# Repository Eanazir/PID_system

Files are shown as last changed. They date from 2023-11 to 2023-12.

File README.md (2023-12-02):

# PID Ball Balancing System

This project is a PID (Proportional, Integral, Derivative) control system designed to balance a ball on a platform. The system utilizes a Raspberry Pi 3 and servo motors to adjust the platform's angle in real-time, maintaining the ball's position.

## Images

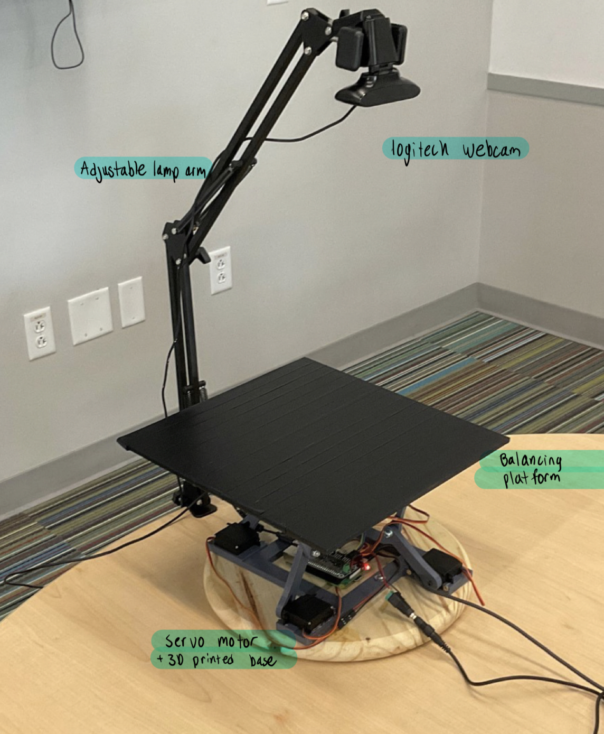
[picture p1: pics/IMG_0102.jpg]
System Overview

*System overview with labeled components.*

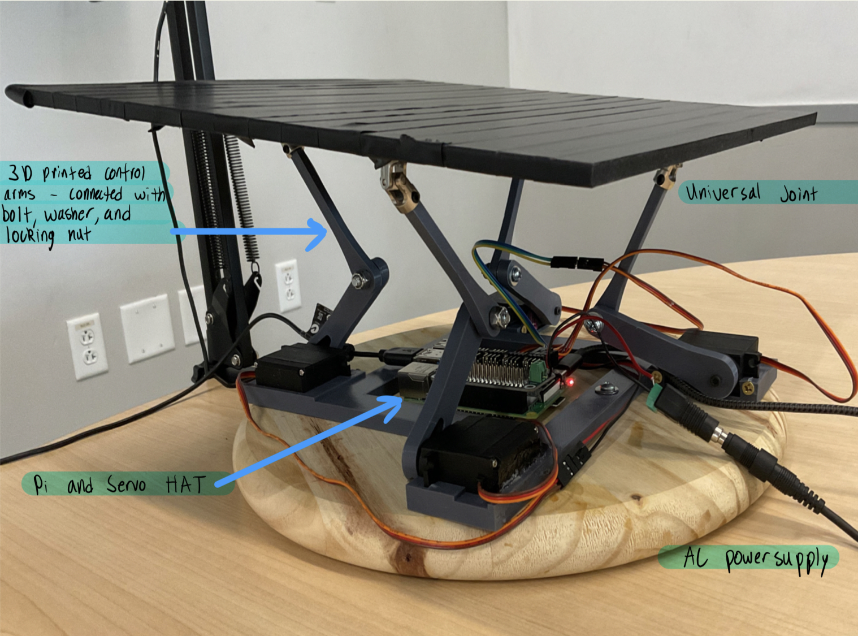
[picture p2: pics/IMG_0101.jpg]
Action Shot

*The PID Ball Balancing System in operation.*

## Bill of Materials

Below is a list of components used in the PID Ball Balancing System, along with their sources and prices.

| Item | Quantity | Source | Price |
|---|---|---|---|
| Servo Motors | 4 | [Amazon](#) | $18.39 |
| Servo Driver HAT | 1 | [Amazon](#) | $18.20 |
| 3D Printed Motor Arm | 4 | FEDC Design Center | N/A |
| 3D Printed Arm | 4 | FEDC Design Center | N/A |
| 3D Printed Base | 1 | FEDC Design Center | N/A |
| 3D Printed Couplers | 4 | FEDC Design Center | N/A |
| Universal Joints | 4 | [Amazon](#) | $10.99 |
| Raspberry Pi 3 | 1 | Provided | N/A |
| Washer Locking Nut Bolt | 4 | [Home Depot](#) | ~$6.00 |
| Wooden Base | 1 | [Home Depot](#) | ~$12.00 |
| Sq. Foot PVC Platform | 1 | [Amazon](#) | $17.47 |
| Adjustable Lamp Arm | 1 | [Amazon](#) | $19.47 |
| Logitech Webcam | 1 | [Amazon](#) | $59.99 |
| 9 V 1 A Power Supply | 1 | Provided | N/A |

## Setup and Configuration

The system's hardware assembly involves mounting the servo motors on the 3D-printed base, connecting the arms, and positioning the Raspberry Pi and camera. Detailed steps for assembly and the software setup can be found in our [Github repository](https://github.com/Eanazir/PID_system).

## System Operation

The PID controller software processes the camera feed to track the ball's position and adjusts the platform's angle using the servo motors to keep the ball centered.

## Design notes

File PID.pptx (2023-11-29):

## PID Ball Balancing

CSCE 462: Eyad Nazir & Hyder Ochsner

## Background

The concept of dynamic stabilization, exemplified in our PID Ball Balancing
project, is a significant leap in control engineering. Drawing inspiration
from advanced earthquake stabilization systems used in modern
infrastructure, this project aims to dynamically control the position
of a ball on a flat surface using a Proportional-Integral-Derivative (PID)
controller. The interplay of hardware components, like servo motors,
and sophisticated software algorithms, echoes the principles of seismic
dampers in skyscrapers. These systems counteract disturbances, such as
seismic waves, by adjusting their structure in real-time. Our project,
while on a smaller scale, mirrors this intricate balance of mechanics and
electronics, and serves as an educational tool in understanding the fundamental principles of vibration control and feedback systems in civil engineering.

## Project goals

- Develop and construct a PID Ball Balancing System to demonstrate the principles of Proportional-Integral-Derivative (PID) control in a hands-on way.
- Integrate mechanical, electrical, and software components to create a dynamic system capable of stabilizing a ball on a tilting platform, showcasing real-world engineering applications.
- Design and implement custom CAD parts, including Motor and Free Arms, for precise system assembly, fostering practical skills in mechanical design and 3D printing.

## System Design

Motor Arm and Free Arm Design
Base Assembly
Motor Bracket Design
Prototype Construction
Circuitry
Software

## Parts Used


- Universal Joint
- Control arms
- AC power Supply
- Raspberry PI 3
- Servo Hat
- Balancing platform
- Servo Motor
- 3d-printed Base
- Adjustable Lamp Arm
- Logitech Camera

## Construction

Pictures along the process

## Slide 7

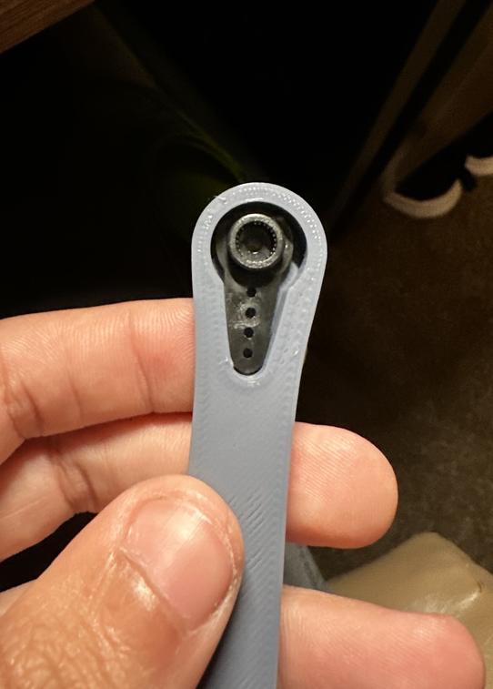
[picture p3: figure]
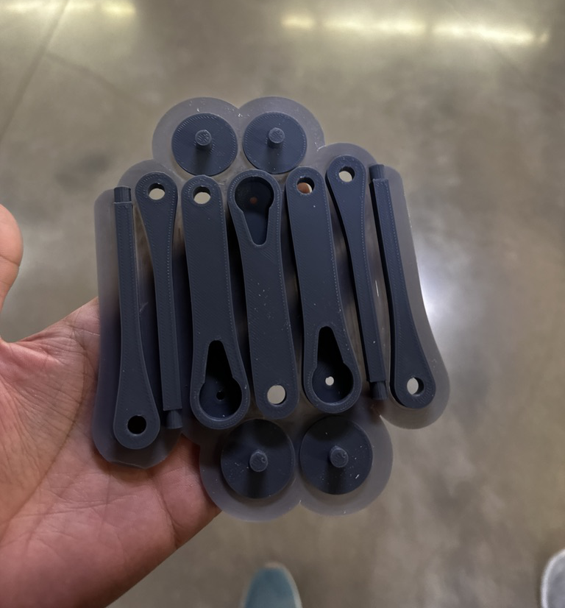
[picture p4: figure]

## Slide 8

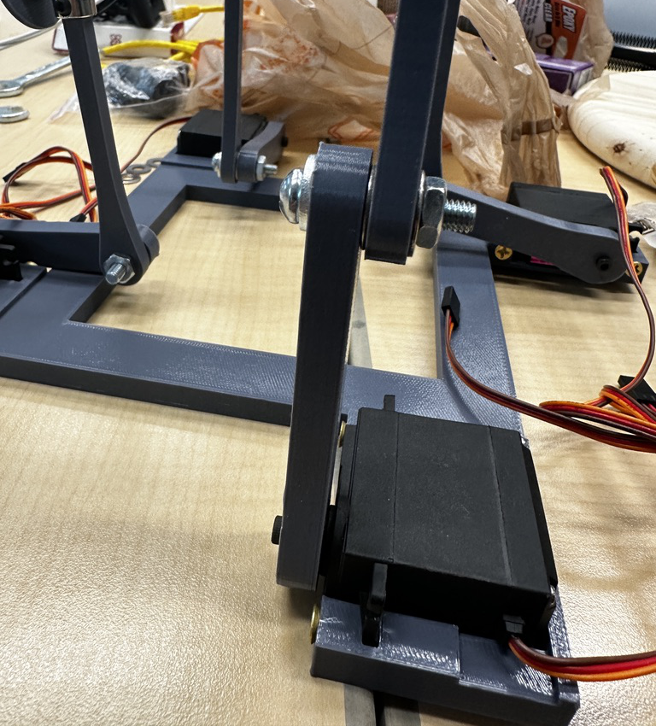
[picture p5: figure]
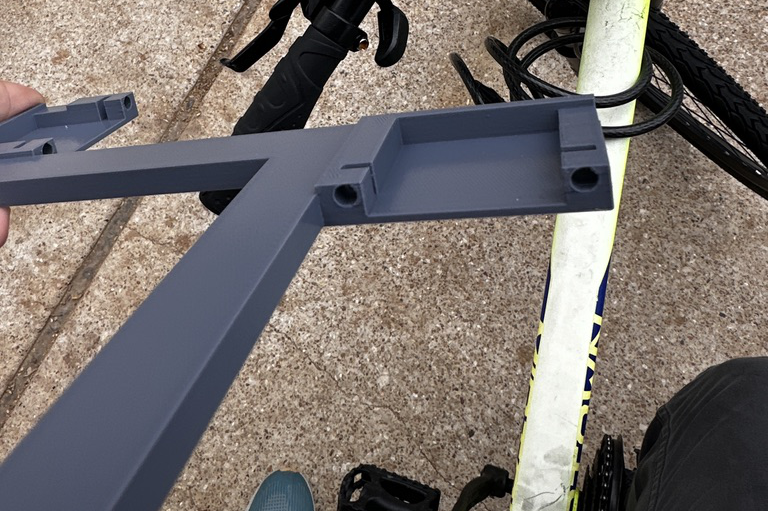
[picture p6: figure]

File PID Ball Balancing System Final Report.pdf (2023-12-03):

# PID Ball Balancing System

# Final ProjectReport Fall 2023

## Hyder Ochsner - Hyder.ochsner@tamu.edu Eyad Nazir - Eanazir@tamu.edu

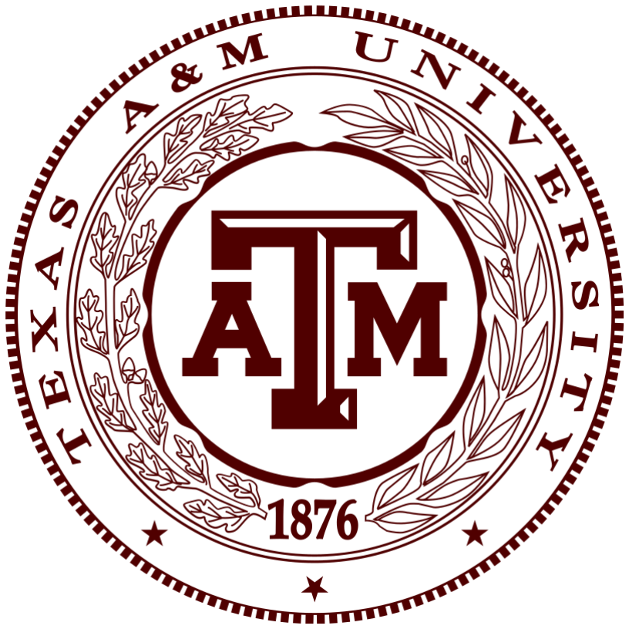
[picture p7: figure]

## Table Of Contents

1. Summary and High-level Description
2. Background
3. Introduction
a. Purpose
b. Environment
c. Constraints
4. System Design
a. Hardware/Mechanical Components
b. Software
5. Design Process
a. Motor Bracket Design
b. Motor Arm and Free Arm Design
c. Base Assembly
d. Prototype Construction
e. Circuitry
f. Software
6. Bill of Materials
7. Appendix (PID Model/Github Link)

Summary and High-level Description

The Ball Balancing PID System project focuses on achieving stabilization and control of a ball on a flat surface through a feedback mechanism. The primary objective is to maintain the ball at a predefined location by continuously measuring its position and adjusting the orientation of the surface. The chosen control mechanism for this project is the Proportional-Integral-Derivative (PID) controller, a widely used feedback controller in industrial control systems. The values calculated by the PID controller are then translated to the angles of the servo motors. Thus allowing for movement of the balancing platform. The project is designed to offer valuable insights into feedback control systems and serves as a practical introduction to PID control, a foundational concept in control engineering.

Background

The concept of dynamic stabilization, exemplified in our PID Ball Balancing project, is a significant leap in control engineering. Drawing inspiration from advanced earthquake stabilization systems used in modern infrastructure, this project aims to dynamically control the position of a ball on a flat surface using a Proportional-Integral-Derivative (PID) controller. The interplay of hardware components, like servo motors, and sophisticated software algorithms, echoes the principles of seismic dampers in skyscrapers. These systems counteract disturbances, such as seismic waves, by adjusting their structure in real-time. Our project, while on a smaller scale, mirrors this intricate balance of mechanics and electronics, and serves as an educational tool in understanding the fundamental principles of vibration control and feedback systems in civil engineering.

Introduction

Purpose
The PID Ball Balancing System, initially developed as a collaborative engineering project, has gained recognition for its educational potential and will be used to provide students with a tool to visualize PID controls, addressing a key engineering problem. By integrating a Raspberry Pi with mechanical components to balance a ball on a tilting platform, the project offers a tangible demonstration of control systems in action. This hands-on approach aids in demystifying complex engineering concepts, particularly in control and feedback mechanisms. As an instructional tool, it not only enhances learning but also encourages innovative thinking in addressing real-world engineering challenges, making it a valuable addition to the educational landscape in engineering and technology.

Environment
The PID Ball Balancing System integrates mechanical, electrical, and software components within a cohesive environment. Its mechanical aspects, primarily the platform and servo motors, interface directly with the physical world. The system's operation is confined within its structured design, encompassing a Raspberry Pi, sensors, and actuators, ensuring stability and precision in its function.

Constraints
The system has a few limiting factors:
1. The Ball needs not to be thrown too fast as the platform will not have the chance to react due to the 60fps nature of the camera
2. The Ball needs not to be thrown at an excessive speed leading it to fall of the platform very quickly
3. The Ball needs to have a desired weight to ensure it does not roll too fast due to the low friction of the platform

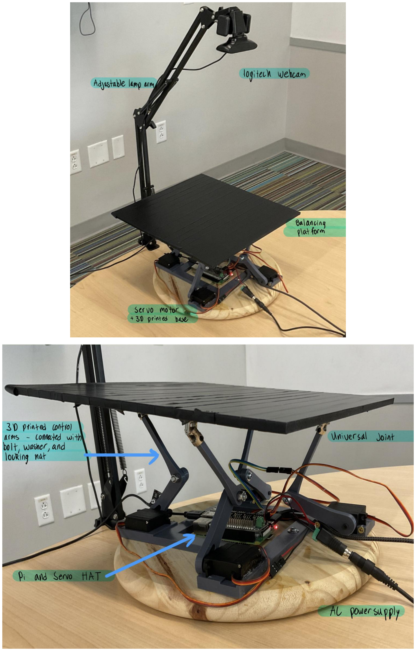
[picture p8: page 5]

System Design

Hardware/Mechanical Components

The system's functionality relies on three main components: servo motors for platform control, the balancing platform, and a camera for ball position tracking. To ensure connectivity between these components, various subcomponents are integrated into the system.

1. Servo Motors and Mounting
The servo motors are mounted on a solid surface to ensure stability during operation. A solid wood plank with a 3D printed bracket is utilized for this purpose. The bracket includes evenly spaced mounts for the four servo motors, each fastened securely to the mount with two screw holes. This configuration eliminates unwanted position shifts of our motors during execution. .
2. Platform Design and Connection to Motors
The platform consists of a lower arm connected to an upper arm at a movable joint, both 3D printed and fastened together using a bolt, washer, and locking nut. The upper arm connects to the platform through a universal joint, allowing the platform to move while maintaining a stable connection with the arm. This design ensures flexibility and stability in the system.
3. Camera Positioning
The camera is positioned above the platform to capture the ball's movement fully and is stabilized to reduce variability. An adjustable lamp arm with a clamp is used for this purpose, providing a steady and adjustable position on the table.

In essence, the hardware and mechanical components are intricately designed and assembled to create a robust system capable of implementing the PID control mechanism for ball balancing. Each component plays a crucial role in ensuring the system's stability and effectiveness in maintaining the ball at the desired location on the flat surface.

Software
The software component of the PID Ball Balancing System is a blend of image processing for ball tracking and intricate PID control logic. This combination exemplifies the project's technical sophistication and educational value.
Image Processing and Ball Tracking: The system uses OpenCV for real-time image analysis. It identifies the ball's position on the platform by analyzing video feed from a camera interfaced with the Raspberry Pi. Our code implements functions to recognize circular shapes and filter out irrelevant contours, ensuring accurate ball tracking. This is crucial for determining the ball's deviation from the desired position. In addition we dynamically search for the center of the platform using contours. We then compare the two centers to find the error.
PID Controller: The core of our system is the PID controller algorithm. The Proportional, Integral, and Derivative components are meticulously tuned to achieve optimal system response. We engaged in an iterative process to determine the PID constants, adjusting them based on the system's performance in various test scenarios.
- Proportional (P) Term: It calculates an output proportional to the current error (the difference between the desired and actual ball position). We experimented with different values to find a balance that minimizes overshoot yet responds swiftly to disturbances.
- Integral (I) Term: This term accumulates the past errors to eliminate residual steady-state error. Finding the right integral constant was crucial to prevent integral windup and ensure smooth corrections over time.
- Derivative (D) Term: It predicts future error trends based on their rate of change, providing damping and improving system stability. Our adjustments in the derivative constant aimed to counteract the ball's motion effectively without inducing unnecessary oscillations.
Our code's sophistication lies in integrating these elements into a cohesive system. We programmed the Raspberry Pi to process the image data, calculate the error in the ball's position, and generate control signals for the servo motors. This interactive loop of sensing, computing, and actuating embodies the intricacies of modern control systems.

Design Process

Stage one: Motor Bracket Design
Upon gathering all the required components for our project, we soon recognized the necessity of custom CAD (Computer-Aided Design) parts for optimal functionality. Our immediate focus was on designing a Motor Bracket, a critical component tasked with securing the servo motors firmly to the base. Given the servos' rapid and continuous movement, precision in the bracket's design was paramount to ensure stable operation without any interference.

Our initial prototype of the Motor Bracket revealed a slight miscalculation: the back-side was designed 2 millimeters too short, resulting in an improper fit for the motors. To rectify this, we quickly adapted our design and extended the back-side by 2 millimeters, ensuring a snug and accurate fit. This adjustment was crucial; it highlighted the importance of precision in mechanical design, especially in a system where even minor discrepancies could significantly impact performance. The redesigned bracket was then 3D printed, marking a successful step in the iterative process of engineering and design refinement. We would then have to come back to add it to the base assembly.

Stage two: Motor Arm and Free Arm Design
Motor Arm is the arm connected to the motor with a very small bolt and then connected to that arm is the Free Arm in which it is held loosely to the Motor arm allowing the flexing and movement of the platform easily. Our initial task was to CAD design the Motor Arm for a precise fit with the motor's hole. However, budget constraints precluded us from producing a high-fidelity print with integrated threads. This limitation led to an issue where the motor shaft would rotate, but the arm remained stationary due to the absence of threads. To overcome this, we revised the design to include a cutout for the Horn, which would be attached directly to the motor. The Motor Arm was then designed to mount onto this Horn, ensuring synchronized movement.

Once this prototype was successfully printed, we proceeded to design and print the Free Arm. This part required only a single iteration, featuring holes at each end for attachment to the Motor Arm and a universal joint, respectively.

We initially used a standard nut to connect the two arms with a bolt and washer. However, we encountered a problem where the rotation of the arm caused the nut to loosen and unscrew. To resolve this, we switched to a locking nut, which provided the necessary stability and prevented the disassembly of the bolt during operation. This adjustment was a critical step in ensuring the reliability and effectiveness of our design.

Stage three: Base Assembly
Following the successful verification of our prototyped parts for fit and compatibility, we shifted our focus to the final CAD assembly, integrating the Motor Brackets with the 6-inch by 6-inch square base. The design called for the placement of one bracket on each side of the base, arranged in a clockwise direction for balanced support and operational efficiency. Each bracket, measuring 2-inches in width, contributed to the total dimensions, extending the length and width of the base to 8-inches at its widest points. This careful consideration in the design ensured a robust and stable structure, essential for the smooth functioning of our system.

Stage four: Prototype Construction
Upon acquiring the essential components, including a wooden base, a base for holding the motors, four Motor Arms, four Free Arms, and some universal joints, we commenced the assembly of our prototype. However, during the construction process, we identified the need for a coupler to link the base with the universal joints. This coupler was designed with one circular end to attach to the joint and another end to be adhered to the platform, which we determined should measure 12 inches by 12 inches for optimal balance and space.
The assembly of the prototype involved meticulously fitting all the arms together using bolts and screws. To enhance the structure's stability, we decided to secure the 3D-printed base to the wooden base using two screws. This step was crucial in ensuring that the base remained firmly anchored, providing a solid foundation for the system's operation and preventing any unwanted movement or instability during testing.
Stage five: Circuitry
The circuitry of our system includes: four servo motors and the servo driver HAT. Upon connecting our components and simple testing, we discovered the motors were not acting as expected as the RaspberryPi’s power source did not produce enough current to power the motors and the Pi. As a result, we connected a power source directly to the servo HAT. After experimenting with multiple 9 V batteries, we concluded the need for AC power supply. We obtained a 9 V, 1 A power supply and the motors performed as expected.

Stage six: Software
The software of our system contains two main components: the PID controller and image processing. We began by researching the necessary libraries and determined the ADAFRUIT Servo library and OpenCV would suffice. We first developed the ball tracking software aimed at detecting the center of our balancing platform and the center of the ping pong ball. We faced numerous challenges due to variations in lighting. To overcome these, we added adjustable options within our program like the ability to select the color of the ball being used and a slider to adjust the brightness threshold.
The PID controller required numerous iterations as the system relies heavily on trial and error.

Bill of Materials

Item | Source | Price
(4x) Servo motors | Amazon (https://www.amazon.com/dp/B0BYD9M1P3?psc=1&ref=ppx_yo2ov_dt_b_product_details) | $18.39
Servo driver HAT | Amazon (https://www.amazon.com/dp/B0BS8PLYZC?psc=1&ref=ppx_yo2ov_dt_b_product_details) | $18.20
(4x) 3D printed Motor Arm | FEDC Design Center | N/A
(4x) 3D printed Free Arm | FEDC Design Center | N/A
3D printed Base | FEDC Design Center | N/A
(4x) 3D printed couplers | FEDC Design Center | N/A
(4x) Universal joints | Amazon (https://www.amazon.com/dp/B07V9NW3V8?ref=ppx_yo2ov_dt_b_product_details&th=1) | $10.99
Raspberry Pi 3 | Provided | N/A
(4x) Washer, locking nut, bolt | Home Depot | ~ $6.00
Wooden base | Home Depot | ~ $12.00
Sq. foot PVC platform | Amazon (https://www.amazon.com/dp/B08N7YJKWD?psc=1&ref=ppx_yo2ov_dt_b_product_details) | $17.47
Adjustable lamp arm | Amazon (https://www.amazon.com/dp/B07X3KMYW2?psc=1&ref=ppx_yo2ov_dt_b_product_details) | $19.47
Logitech webcam | Amazon (https://www.amazon.com/Logitech-C920x-Pro-HD-Webcam/dp/B085TFF7M1?s=electronics) | $59.99
9 V, 1 A power supply | Provided | N/A

Appendix (PID Model/Github Link)
- Github link: https://github.com/Eanazir/PID_system

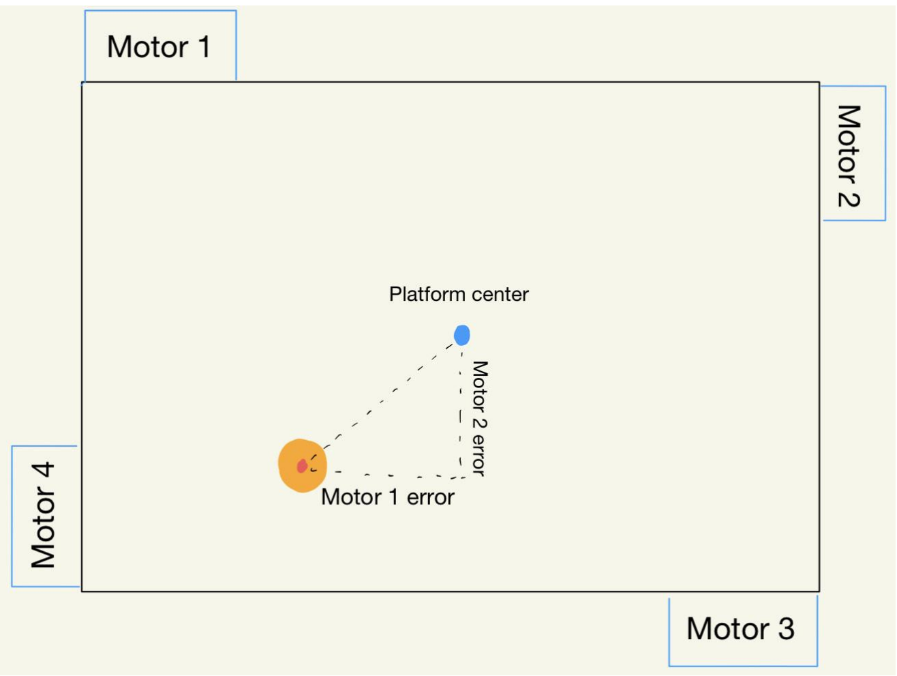
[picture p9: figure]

- Error Calculation:
- Motor 1 (Top edge) Error[1] = Ball | :
y − Platformy
calculates the vertical distance between the ball's current and desired positions. A positive error indicates the ball is below the desired position, requiring the top edge to lift.
- Motor 2 (Right edge) Error[2] = Ball | :
x − Platformx
measures the horizontal distance on the right side. A positive error suggests the ball is left of the desired position, necessitating the right edge to lift.
- Motor 3 (Bottom edge): Error[3] = Platform | : y − Ball y
is similar to Motor 0 but for the bottom edge. A positive error means the ball is above the desired position, signaling the bottom edge to lift.
- Motor 4 (Left edge): Error[4] = Platformx − Ball
| x :
assesses the horizontal distance on the left side. A positive error indicates the ball is to the right of the desired position, requiring the left edge to lift.

- PID = K
p

× Error + K
i

× ∫ Error dt + Kd
×

d(Error)
dt
- Proportional (P) Term (Kp): Determines the reaction to the current error. If the ball is far from the desired position, a large correction is made.
- Integral (I) Term (Ki): Addresses the accumulation of past errors (integral of the error), helping to eliminate residual steady-state error.
- Derivative (D) Term (Kd): Predicts future error trajectory based on its rate of change, providing a dampening effect to avoid overshooting.
- The PID value would be negative when the motor needed to tilt the platform up and positive when the motor needed to tilt the platform down.
Note: The tuning process is often iterative, and it involves finding the right balance between the three terms to achieve stability, fast response, and minimal overshoot or oscillation. This process relies heavily on trial and error.
- New Angle = Initial Angle +

PID
Scaling Factor
- The New Angle here is calculated based on its initial angle plus the PID number divided by a scaling factor that was obtained by trial and error. This was done for each motor.
- For our hardware as the angle increased the motor arm went down decreasing the platform level.

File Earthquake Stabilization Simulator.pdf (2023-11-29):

## Earthquake Stabilization Simulator

Team Members:
- Hyder Ochsner - System Design Engineer: (hyder.ochsner@tamu.edu)
- Responsibilities:
■ Responsible for the overall system architecture, component selection, and ensuring that all components work together seamlessly
- Eyad Nazir - Software & Control Engineer: (eanazir@tamu.edu)
- Responsibilities:
■ Responsible for writing the software that will run on the microcontroller, implementing the PID algorithm, and programming any additional features such as the bouncing patterns
Summary:
The Ball Balancing PID System project aims to stabilize and control the position of a ball on a flat surface using a feedback mechanism. By constantly measuring the ball's position and adjusting the surface's orientation, the system maintains the ball at a predefined location, even when disturbed. The control mechanism employed is a Proportional-Integral-Derivative (PID) controller, a popular type of feedback controller in industrial control systems. This project provides valuable insights into feedback control systems and can serve as a practical introduction to PID control, one of the foundational concepts in control engineering.

Technical Description:
1. Components:
- Platform: A flat surface on which the ball rolls. This can be controlled using actuators to tilt in various directions
- Ball: A spherical object that rolls on the platform
- Sensors: To detect the ball's position. Common choices include infrared sensors, ultrasonic sensors, or cameras
- Actuators: Mechanisms that can tilt the platform in response to control signals. Typically, servos or motors are used
- Microcontroller: A device that processes sensor data, implements the PID algorithm, and controls the actuators
2. Working:
- The sensors constantly measure the ball's position on the platform and send this data to the microcontroller
- The microcontroller calculates the error, which is the difference between the ball's current position and the desired position
- Using the PID algorithm, the controller calculates the necessary adjustments to make to the platform's orientation

- The actuators adjust the platform's tilt based on the controller's signal, moving the ball towards the desired position
3. PID Controller:
- Proportional (P): This component produces an output value proportional to the current error. It determines the reaction to the current error
- Integral (I): Concerned with the accumulation of past errors. If the error has been present for an extended period, it will accumulate (integral of the error), and the controller will respond by changing the control output in relation to a sustained error
- Derivative (D): This predicts the future error trajectory based on its rate of change. It provides a control output to counteract the rate of error change
4. Features:
- To design and develop a system that can dynamically adjust its position to counteract disturbances, simulating the behavior of advanced earthquake stabilization systems used in modern infrastructure
- System will include programmed bouncing patterns which when executed will bounce the ball in a predefined rhythm
- Sync the bouncing action with music or sound effects. For example, the ball can bounce to the beat of a song, turning the system into an interactive musical instrument

High-level design:

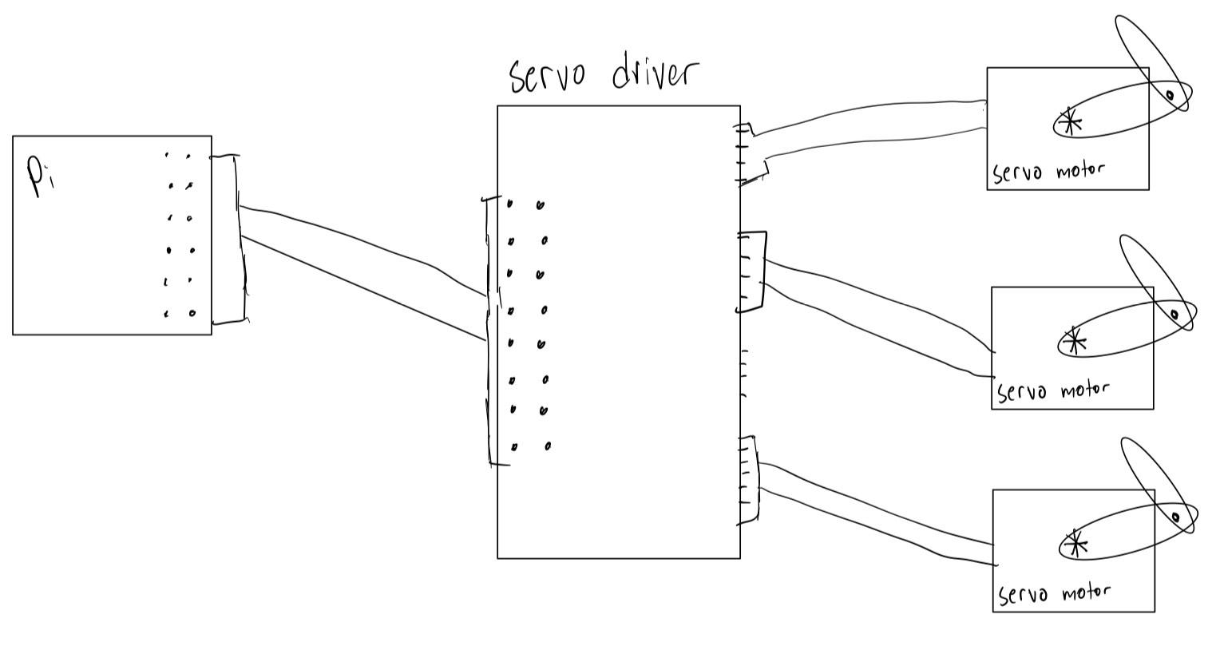
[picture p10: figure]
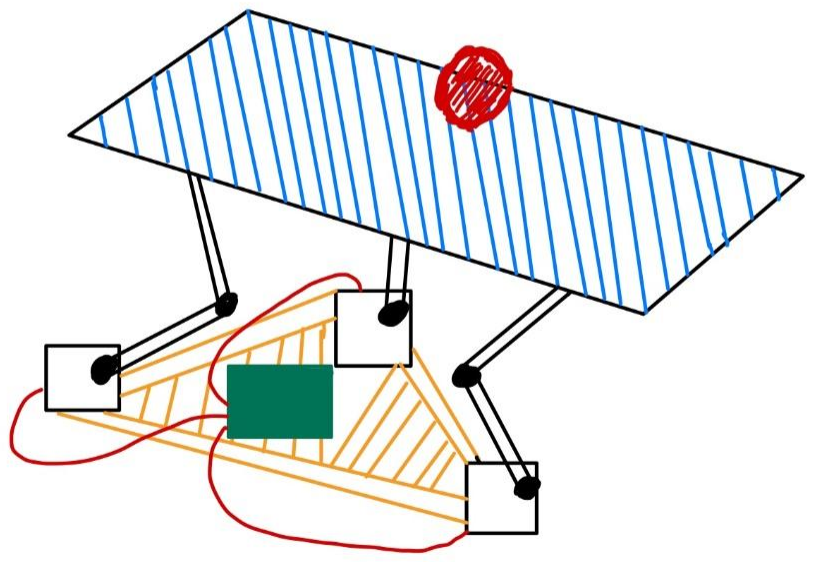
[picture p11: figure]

Expected Materials:
- RaspberryPi (Already Owned)
- Camera Extension Cable ($7.42)
- https://www.amazon.com/Adafruit-Flex-Cable-Raspberry-Camera/dp/B00XW2NCKS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
- RaspberryPi Camera ($24.71)
- https://www.amazon.com/Raspberry-Pi-Camera-Module-Megapixel/dp/B01ER2SKFS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
- Servo Driver HAT for Raspberry Pi ($18.25)

- https://www.amazon.com/waveshare-Raspberry-16-Channel-Interface-Pinheader/dp/B07XKGHJ8B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
- Servo Motors (x4 for $14.92)
- https://www.amazon.com/diymore-MG90S-Digital-Servos-Helicopter/dp/B07NV7SD3F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 (https://www.amazon.com/diymore-MG90S-Digital-Servos-Helicopter/dp/B07NV7SD3F)
- 3D Printed Control Arms (~ $10)
- 3D Printed Flat Plane (~ $8)

Technical Requirements and challenges: Mechanical:
- Design a stable base for the servo motors so that they are in a fixed position to minimize error
- Ensure the control arms are securely fastened to the flat platform
- Have the RaspberryPi camera in a fixed position so that there is no variation in repeated tests
- Utilized contrasting colors between the ball and platform so the positioning is easily detectable
- 3d printing the platform and the movable arms, which proposes the problem of working with CAD software and keeping costs down.
- Camera - Have a viable camera that is able to properly recognize the ball movement and transmit data onto PI
Software:
- Utilize OpenCV to track the location of the ball and determine the difference in the current position compared to the center of the plane
- With the calculated errors in the position, pass the necessary output necessary for each servo using the AdaFruit Servo library
- Design a PID algorithm which is capable of performing the outlined features with minimal error
Hardware:
- Wiring the mechanical moving arms to the breadboard might include either soldering or using the mentioned wire casings in class that connect multiple wires
- Bolts will be needed to connect the mechanical arm sections together to allow for flexible movement.

Workplan:
Week 0: Initial Preparation & Team Coordination:
- Objective: Establish communication, understand roles, and set preliminary goals.
Tasks:
1. Meet and understand the roles of System Design Engineer (SDE) and Software & Control Engineer (SCE).
2. Discuss the project's vision, goals, and preliminary design ideas.

3. Set up a shared workspace (online or physical) for collaboration and documentation.

Week 1: Planning, Research & Acquisition (Phases 1 & 2):
- Objective: Set specific objectives and secure all necessary components.
Tasks:
1. Define the project's detailed objectives and desired outcomes.
2. SDE to research and order components: sensors, actuators, microcontroller, etc.
3. SCE to set up the software development environment and begin preliminary research on PID algorithms.

Week 2: Assembly & Initial Software Development:
- Objective: Begin hardware assembly and foundational software development.
Tasks:
1. SDE to assemble the basic platform and install actuators.
2. SCE to develop software for sensor data collection and basic actuator control.
3. Test the platform's response to simple software commands.

Week 3: PID Implementation & Calibration:
- Objective: Implement the PID algorithm and begin calibrations.
Tasks:
1. SCE to finalize and test the PID algorithm.
2. SDE to assist in calibrating the system by adjusting the platform and observing the ball's behavior.
3. Jointly conduct initial system tests and document results.

Week 4: Advanced Features & Debugging:
- Objective: Implement advanced features like bouncing patterns and identify any system issues.
Tasks:
1. SCE to program bouncing patterns and synchronization with music.
2. SDE to adjust and optimize the platform's hardware to accommodate these new features.
3. Identify, document, and resolve any emerging issues.

Week 5: Integration & System Testing:
- Objective: Integrate all system components and conduct comprehensive testing. Tasks:
1. SCE to finalize the software, ensuring all features work cohesively.
2. SDE to finalize the hardware, ensuring it responds well to software controls.
3. Conduct thorough system tests, recording performance and identifying areas of improvement.

Week 6: Final Adjustments & Documentation:
- Objective: Make final adjustments and document the entire project.

Tasks:
1. Make any final tweaks to the software or hardware based on testing feedback.
2. Document the project, including schematics, code comments, user manual, and potential future enhancements.
3. Conduct a project review meeting to discuss successes, challenges, and learnings.

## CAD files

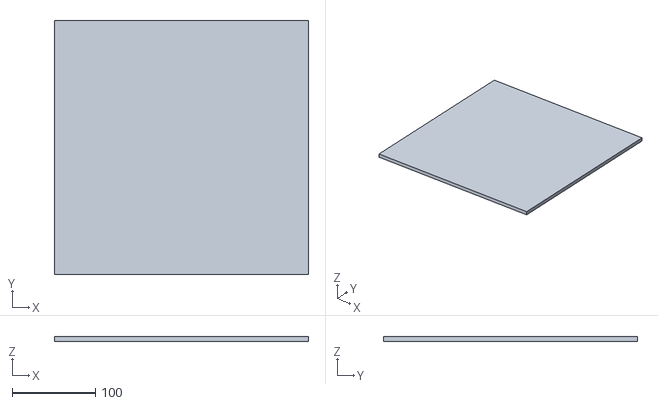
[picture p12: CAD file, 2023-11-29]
3d_prints/platform v1.stl
304.8 x 304.8 x 6.00

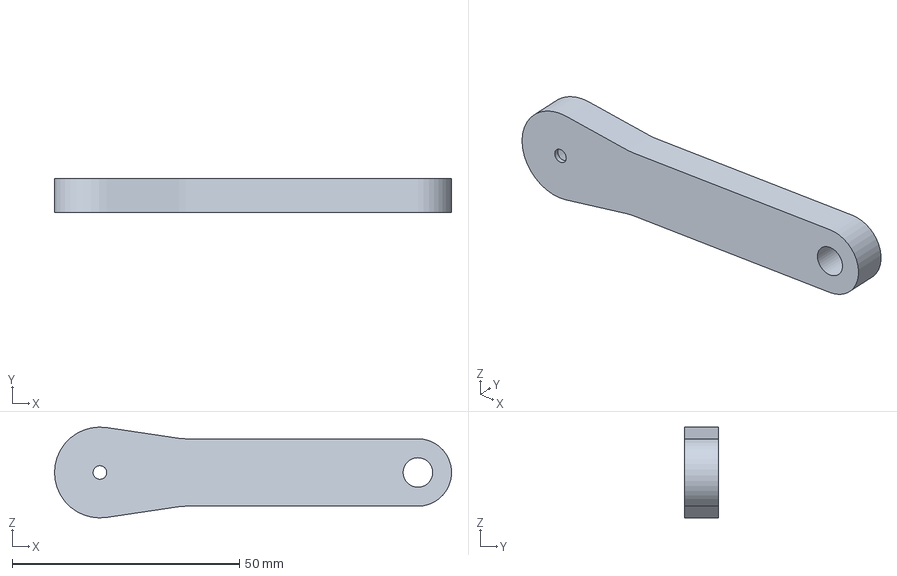
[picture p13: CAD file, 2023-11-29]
3d_prints/Arm_proto3_3.3MF
87.4 x 7.50 x 20.0 mm

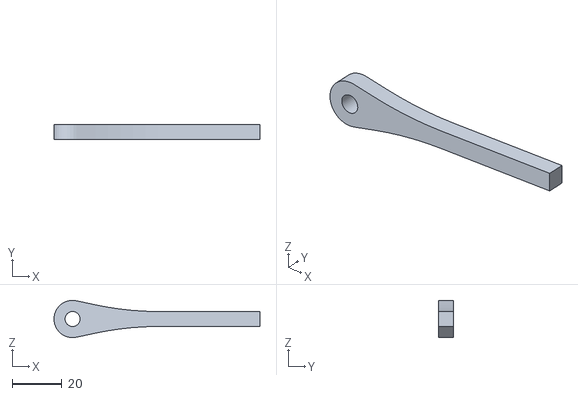
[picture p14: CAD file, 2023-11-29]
3d_prints/Arm2.stl
82.4 x 5.90 x 14.9

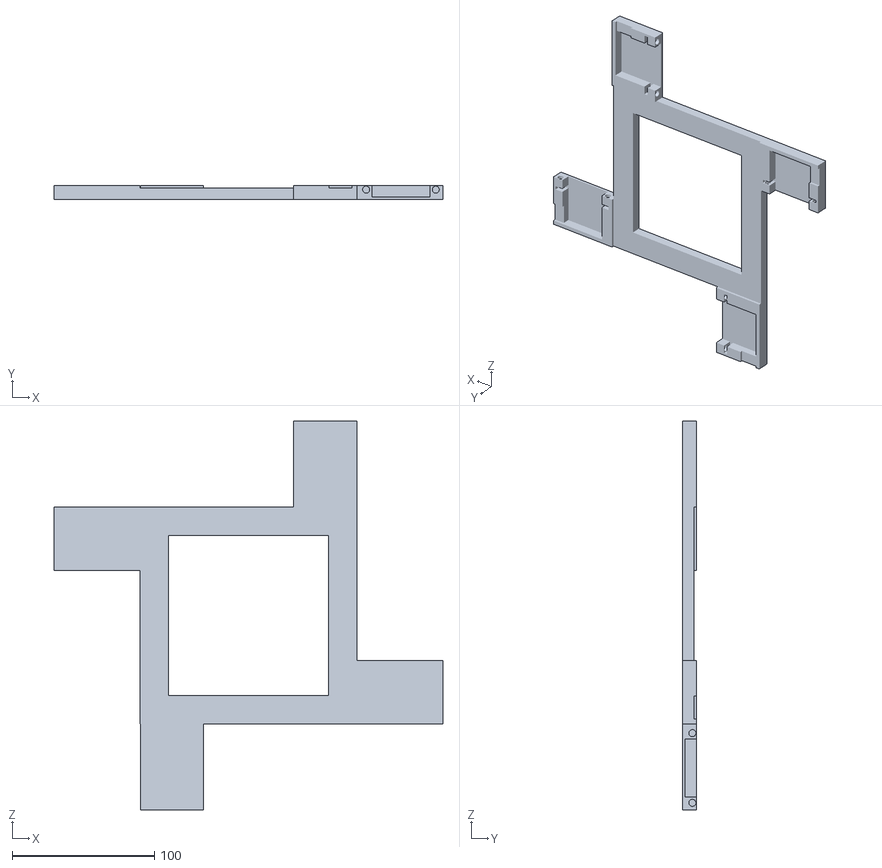
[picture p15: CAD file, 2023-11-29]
3d_prints/base_save v3.stl
273.8 x 10.0 x 273.8

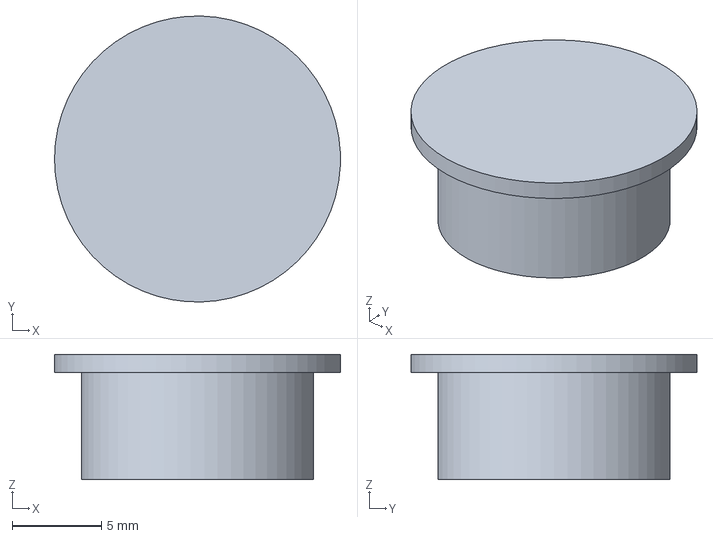
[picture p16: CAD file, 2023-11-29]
3d_prints/coupler.3MF
16.0 x 16.0 x 7.00 mm

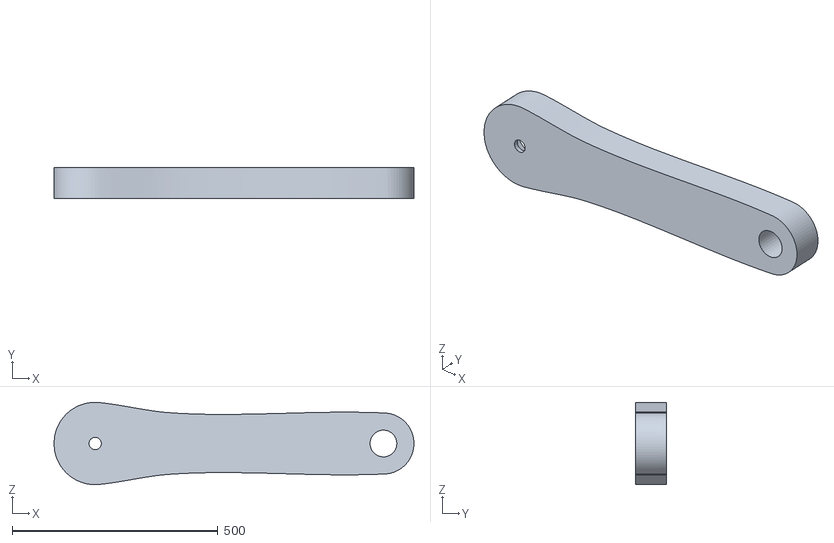
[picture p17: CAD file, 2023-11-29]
3d_prints/Arm1 v2.stl
874.2 x 75.0 x 200.0

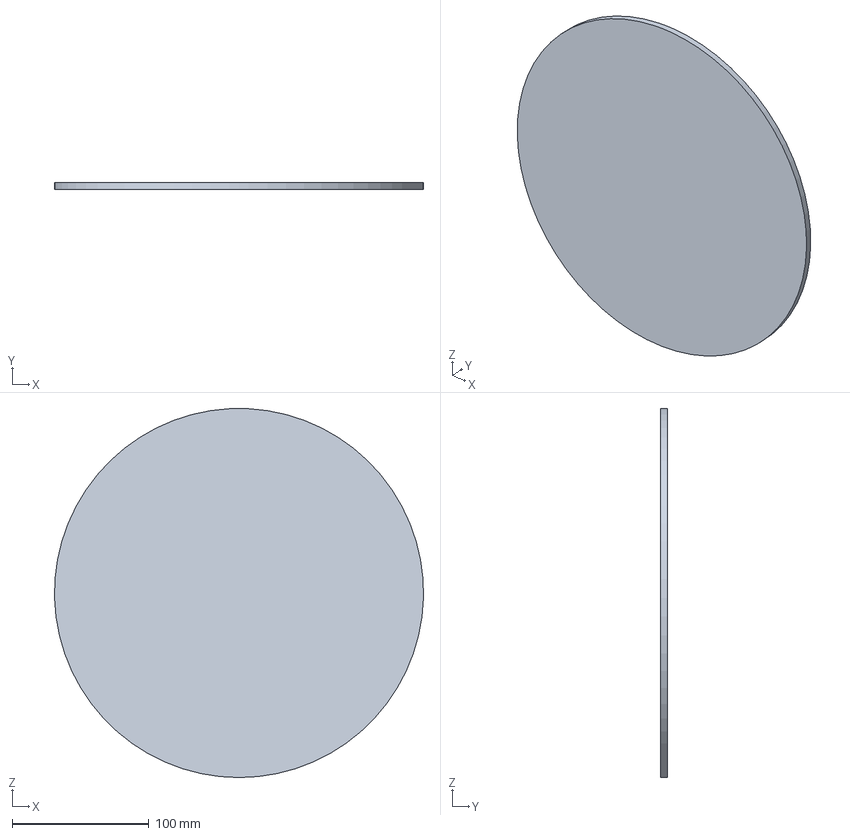
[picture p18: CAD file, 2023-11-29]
3d_prints/PLATEAU.3MF
269.9 x 5.00 x 270.0 mm

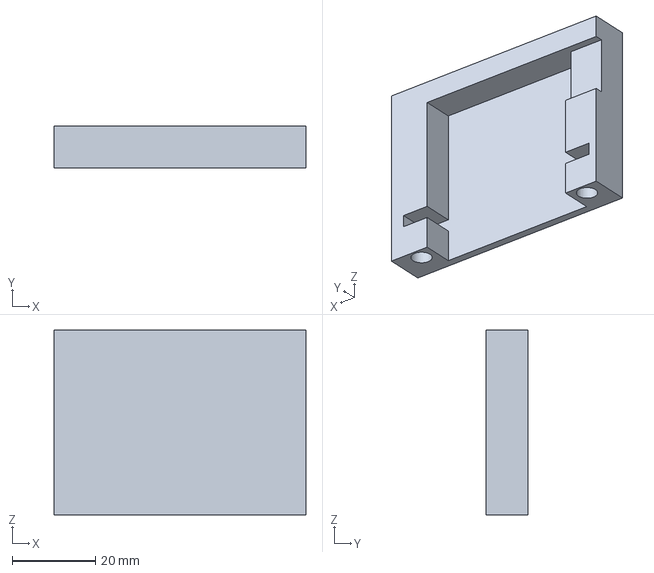
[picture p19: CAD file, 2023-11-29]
3d_prints/Servo_bracket_proto2.3MF
60.7 x 10.0 x 44.5 mm

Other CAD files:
3d_prints/Arm2_proto3.3MF
3d_prints/Arm_proto3_2.3MF
3d_prints/base_save v1.stl
3d_prints/base_save v2.f3d

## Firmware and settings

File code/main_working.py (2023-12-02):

import cv2
import numpy as np
import time
import sys
from adafruit_servokit import ServoKit

kit = ServoKit(channels=16)
kit.servo[0].set_pulse_width_range(500,2500)
kit.servo[1].set_pulse_width_range(500,2500)
kit.servo[2].set_pulse_width_range(500,2500)
kit.servo[3].set_pulse_width_range(500,2500)


def nothing(x):
    pass

def prompt_for_pid_values():
    global Kp, Ki, Kd
    try:
        new_kp = float(input("Enter new Kp value for all motors: "))
        new_ki = float(input("Enter new Ki value for all motors: "))
        new_kd = float(input("Enter new Kd value for all motors: "))
        Kp = np.array([new_kp, new_kp, new_kp, new_kp])
        Ki = np.array([new_ki, new_ki, new_ki, new_ki])
        Kd = np.array([new_kd, new_kd, new_kd*1.5, new_kd])
    except ValueError:
        print("Invalid input, using previous values.")


initial_angle = [135, 131, 131, 135]  # Initial angles for the motors
def adjust_motor_angles():
    window_name = "Motor Angle Adjuster"
    cv2.namedWindow(window_name, cv2.WINDOW_NORMAL)
    cv2.resizeWindow(window_name, 500, 200)

    # Create trackbars for each motor
    min_angle = 105
    max_angle = 155
    angles = [135, 135, 135, 135]  # Initial angles for the motors
    
    def update_angle(index, value):
        angle = min_angle + value  # Adjusting the value to the correct range
        angles[index] = angle
        kit.servo[index].angle = angle
        print(f"Motor {index+1} angle set to: {angle}")

    for i in range(4):
        cv2.createTrackbar(f"Motor {i+1}", window_name, 0, max_angle-min_angle, lambda x, i=i: update_angle(i, x))
        cv2.setTrackbarPos(f"Motor {i+1}", window_name, angles[i] - min_angle)  # Adjust trackbar position to the correct range


    # Wait until 'q' is pressed to close the adjustment window
    while True:
        key = cv2.waitKey(1) & 0xFF
        if key == ord('q'):
            break
    cv2.destroyAllWindows()

# Initialize the camera
cap = cv2.VideoCapture(0)
cap.set(cv2.CAP_PROP_FRAME_WIDTH, 640)
cap.set(cv2.CAP_PROP_FRAME_HEIGHT, 480)

# Check if the camera opened successfully
if not cap.isOpened():
    print("Error: Camera is not opened")
    exit()

# Variables to store the ROI coordinates
roi = [0, 0, 0, 0]
drawing = False  # True if mouse is pressed

# Function to send control signal to the servos
# Placeholder function, replace with your implementation
min_motor = np.array([120,120,120,120])
max_motor = np.array([150,150,150,150])

# kit.servo[0].angle = initial_angle[0]
# kit.servo[1].angle = initial_angle[1] 
# kit.servo[2].angle = initial_angle[2] 
# kit.servo[3].angle = initial_angle[3]

kit.servo[0].angle = 155
kit.servo[1].angle = 111
kit.servo[2].angle = 136
kit.servo[3].angle = 155
def move_motors(pid):
    for i in range(0,4,1):
        print("pid " + str(i) + " " + str(pid[i])) 
        angle = initial_angle[i] + (pid[i]/40)
        angle = np.floor(angle)
        print("angle " + str(angle))
        if angle > max_motor[i]:
            print("angle limit high")
            angle = max_motor[i]
        if angle < min_motor[i]:
            print("angle limit low")
            angle = min_motor[i]
        kit.servo[i].angle = angle 


# Placeholder for your servo control logic
# This function needs to be implemented based on your servo setup
lastderivative = 0
lastlastderivative = 0
derivative = 0
integral = 0
pid = 0
def control_servos():
    global start_time
    global computation_time
    global errors, pasterrors
    global lastderivative, lastlastderivative, derivative
    global Ki
    global integral
    comp_time = time.time() - start_time
    computation_time.append(comp_time)
    if np.all(errors > 10):
        integral += errors * 0.5 
    else:
        integral = 0
    Kd_normalized = np.copy(Kd)
    Ka_normalized = np.copy(Ka)
    Kp_normalized = np.copy(Kp)
#     Kp_normalized[np.abs(errors) < 50] = Kp_normalized[np.abs(errors) < 50] * 0.5

    
    print("kd: " + str(Kd_normalized) + " kp: " + str(Kp_normalized) + " ki: " + str(Ki) + " ka: " + str(Ka_normalized))
    
    lastlastderivative = np.copy(lastderivative)
    lastderivative = np.copy(derivative)
    derivative = (errors - pasterrors)
    
    if np.sum(abs(derivative)) < 30:
        Kd_normalized = Kd_normalized *  0.1
    # elif np.sum(abs(derivative)) > 20:
    #     Kd_normalized = Kd_normalized * 1.1
    if np.all(np.abs(derivative) < 0.5):
        Kd_normalized = 0
    
    pid = Kp_normalized * errors + Ki * integral + Kd_normalized * derivative + Ka_normalized * (((derivative - lastderivative) + (lastderivative - lastlastderivative))/2.0)
    print("Pid: ", pid)
    
    move_motors(pid)
    
    pass


# Mouse callback function
def draw_roi(event, x, y, flags, param):
    global roi, drawing

    # If left mouse button clicked, record the starting ROI coordinates
    if event == cv2.EVENT_LBUTTONDOWN:
        drawing = True
        roi = [x, y, x, y]

    # If mouse is moved, record the ending ROI coordinates
    elif event == cv2.EVENT_MOUSEMOVE:
        if drawing:
            roi[2], roi[3] = x, y

    # If left mouse button is released, complete the rectangle
    elif event == cv2.EVENT_LBUTTONUP:
        drawing = False
        roi[2], roi[3] = x, y

# Create a window and attach the mouse callback function
cv2.namedWindow("Frame")
cv2.setMouseCallback("Frame", draw_roi)

print("Draw ROI rectangle with the mouse and press 'c' to confirm")

# Loop for drawing the ROI
while True:
    ret, frame = cap.read()
    if not ret:
        print("Failed to capture the image")
        break

    # Draw the ROI rectangle on the frame
    if drawing or roi[2]:
        cv2.rectangle(frame, (roi[0], roi[1]), (roi[2], roi[3]), (0, 255, 0), 2)

    cv2.imshow("Frame", frame)

    key = cv2.waitKey(1) & 0xFF
    if key == ord('q'):
        cap.release()
        cv2.destroyAllWindows()
        exit()
    elif key == ord('c'):  # Press 'c' to confirm the ROI and continue
        if roi[2] and roi[3]:
            break

# Close the initial window
cv2.destroyAllWindows()

# Define ROI coordinates
x_start, y_start, x_end, y_end = roi
x_start, x_end = sorted([x_start, x_end])
y_start, y_end = sorted([y_start, y_end])


# Predefined HSV color ranges for ball tracking
color_ranges = {
    'blue': ([100, 150, 0], [140, 255, 255]),
    'green': ([40, 70, 70], [80, 255, 255]),
    'orange': ([5, 50, 50], [15, 255, 255]),
    'yellow': ([25, 100, 100], [35, 255, 255])
}

# Prompt for ball color input
print("Enter the color of the ball: (blue, green, orange, yellow)")
selected_color = input().lower()
lower_hsv, upper_hsv = color_ranges.get(selected_color, ([0, 0, 0], [179, 255, 255]))
lower_hsv = np.array(lower_hsv)
upper_hsv = np.array(upper_hsv)

# Create a window for the slider
cv2.namedWindow("Threshold Adjuster", cv2.WINDOW_NORMAL)
cv2.resizeWindow("Threshold Adjuster", 300, 50)  # Width, Height
cv2.createTrackbar("Threshold", "Threshold Adjuster", 0, 255, nothing)
cv2.setTrackbarPos("Threshold", "Threshold Adjuster", 200) # Default value
# Flag to indicate if the threshold is being manually adjusted
manual_threshold = False



# PID constants

Kp = np.array([1, 1, 1, 1])
Ki = np.array([5, 5, 5, 5])
Kd = np.array([30, 30, 30, 30])
Ka = np.array([0, 0, 0, 0])  # Acceleration factor

# PID variables
previous_error_x = 0
previous_error_y = 0
integral_x = 0
integral_y = 0

# Desired position (setpoint) is the center of the platform
# These will be updated once we have the ROI
desired_position_x = 0  # Placeholder, will be set later
desired_position_y = 0  # Placeholder, will be set later



# Main control loop
start_time = time.time()
errors = np.zeros(4)
pasterrors = np.zeros(4)
computation_time = []
paused = False
while True:
    ret, frame = cap.read()
    if not ret:
        print("Failed to capture the image")
        break
    frame = frame[y_start:y_end, x_start:x_end]
    # Convert frame to HSV and create a mask
    hsv = cv2.cvtColor(frame, cv2.COLOR_BGR2HSV)
    mask = cv2.inRange(hsv, lower_hsv, upper_hsv)  
    
    # Find contours in the mask
    contours, _ = cv2.findContours(mask.copy(), cv2.RETR_EXTERNAL, cv2.CHAIN_APPROX_SIMPLE)
    
    # Assume no ball found yet
    ball_position_x, ball_position_y = None, None

    if contours:
        # Find the largest contour and use it as the ball
        largest_contour = max(contours, key=cv2.contourArea)
        ((x, y), radius) = cv2.minEnclosingCircle(largest_contour)
        
        # Consider the ball found if the radius meets a minimum size
        if radius > 10:
            ball_position_x, ball_position_y = int(x), int(y)
            # Draw the circle on the ball
            cv2.circle(frame, (ball_position_x, ball_position_y), int(radius), (0, 255, 0), 2)
            cv2.circle(frame, (ball_position_x, ball_position_y), 5, (0, 0, 255), -1)
    
    # Check if manual threshold adjustment is enabled
    if manual_threshold:
        threshold_value = cv2.getTrackbarPos("Threshold", "Threshold Adjuster")
    else:
        # Implement dynamic thresholding based on lighting condition
        # Example: Calculate average brightness of the image and set threshold
        avg_brightness = np.mean(cv2.cvtColor(frame, cv2.COLOR_BGR2GRAY))
        threshold_value = int(avg_brightness * 2)  # Example calculation

    # Platform center tracking with adjusted threshold
    gray = cv2.cvtColor(frame, cv2.COLOR_BGR2GRAY)
    blur = cv2.GaussianBlur(gray, (5, 5), 0)
    _, thresh = cv2.threshold(blur, threshold_value, 255, cv2.THRESH_BINARY_INV)
    contours, _ = cv2.findContours(thresh, cv2.RETR_EXTERNAL, cv2.CHAIN_APPROX_SIMPLE)

    if contours and cv2.contourArea(max(contours, key=cv2.contourArea)) > 100:
        largest_contour = max(contours, key=cv2.contourArea)
        M = cv2.moments(largest_contour)
        if M["m00"] != 0:
            desired_position_x = int(M["m10"] / M["m00"])
            desired_position_y = int(M["m01"] / M["m00"])
            cv2.circle(frame, (desired_position_x, desired_position_y), 5, (255, 0, 0), -1)
            cv2.drawContours(frame, [largest_contour], -1, (255, 0, 0), 2)

    # Display the resulting frame
    
    
    # Only proceed with PID control if we have a ball position
    if ball_position_x is not None and ball_position_y is not None:
        # Calculate error between desired position and current ball position
        error_x = desired_position_x - ball_position_x
        error_y = desired_position_y - ball_position_y

        # Calculate integral for Ki term
        integral_x += error_x
        integral_y += error_y

        # Calculate derivative for Kd term
        derivative_x = error_x - previous_error_x
        derivative_y = error_y - previous_error_y

        # Calculate control signals
        control_signal_x = Kp*error_x + Ki*integral_x + Kd*derivative_x
        control_signal_y = Kp*error_y + Ki*integral_y + Kd*derivative_y

        # Update previous error
        previous_error_x = error_x
        previous_error_y = error_y
        
        pasterrors = np.copy(errors)

        # Error calculation:
        # Positive error indicates the ball is below the motor position for Y-axis motors
        # and to the left of the motor position for X-axis motors
        errors[0] = y - desired_position_y  # Error for Motor 0 (Top edge)
        errors[1] = desired_position_x - x  # Error for Motor 1 (Right edge)
        errors[2] = desired_position_y - y  # Error for Motor 2 (Bottom edge)
        errors[3] = x - desired_position_x  # Error for Motor 3 (Left edge)

        control_servos()
        print("current ball: ( " + str(ball_position_x) + ", " + str(ball_position_y) + " ) platform center: (" + str(desired_position_x) + ", " + str(desired_position_y) + " ) error: (" + str(error_x) + ", " + str(error_y) + ")")


    cv2.imshow('Combined Tracking', frame)
        
    key = cv2.waitKey(1) & 0xFF
    if key == ord('q'):
        break
    elif key == ord('t'):
        manual_threshold = not manual_threshold
    elif key == ord('a'):  # If 'a' is pressed, show motor angle adjuster
        adjust_motor_angles()
    elif key == ord('y'):
        cap.release()
        cv2.destroyAllWindows()
        prompt_for_pid_values()
        cap = cv2.VideoCapture(0)  # Reinitialize the camera
        cap.set(cv2.CAP_PROP_FRAME_WIDTH, 640)
        cap.set(cv2.CAP_PROP_FRAME_HEIGHT, 480)
        continue
            
# Cleanup
cap.release()
cv2.destroyAllWindows()

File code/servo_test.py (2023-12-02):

from adafruit_servokit import ServoKit
from board import SDA, SCL
import busio
from adafruit_pca9685 import PCA9685
from time import sleep


# i2c = busio.i2c(SCL, SDA)

# pca = PCA9685(i2c)

# pca.frequency = 60

kit = ServoKit(channels=16)

# kit.servo[0].actuation_range = 360
kit.servo[0].set_pulse_width_range(500,2500)
kit.servo[1].set_pulse_width_range(500,2500)
kit.servo[2].set_pulse_width_range(500,2500)
kit.servo[3].set_pulse_width_range(500,2500)
# kit.servo[0].angle = 180
# kit.continuous_servo[0].throttle = 1

# kit.continuous_servo[0].throttle = -1
# sleep(2)
# kit.continuous_servo[0].throttle = 0

# kit.servo[0].angle = 0

def resetPattern():
    kit.servo[0].angle = 135
    kit.servo[4].angle = 135
    kit.servo[8].angle = 135
    kit.servo[12].angle = 135
    
def goDownPattern():
    kit.servo[0].angle = 155
    kit.servo[4].angle = 155
    kit.servo[8].angle = 155
    kit.servo[12].angle = 155
    
def pattern1():
    kit.servo[0].angle = 155
    kit.servo[4].angle = 142
    kit.servo[8].angle = 115
    kit.servo[12].angle = 140
    
def pattern2():
    kit.servo[0].angle = 142
    kit.servo[4].angle = 115
    kit.servo[8].angle = 128
    kit.servo[12].angle = 155
    
    
def pattern4():
    kit.servo[8].angle = 155
    kit.servo[0].angle = 115
    kit.servo[4].angle = 135
    kit.servo[12].angle = 145


while True:
    a0 = input("Enter 0: ")
    kit.servo[0].angle = int(a0)
    a1 = input("Enter 1: ")
    kit.servo[1].angle = int(a1)
    a2 = input("Enter 2: ")
    kit.servo[2].angle = int(a2)
    a3 = input("Enter 3: ")
    kit.servo[3].angle = int(a3)
    
    
    
    #tilt -y:
    # 0: down  most (increase ansgle) + 10
    # 1: up half (decrease angle) -5
    # 2: up most (decrease angle) -10
    # 3: down half (increase angle) + 5

# resetPattern()
# sleep(2)
# kit.servo[4].angle = 125
# kit.servo[8].angle = 125
# sleep(.05)  
# kit.servo[4].angle = 115
# sleep(.05)
# kit.servo[12].angle = 145
# kit.servo[0].angle = 145
# kit.servo[12].angle = 155
# sleep(2)


# count12 = 0
# count0=0
# count4=0
# count8=0
# while True:
#     if (count12 < 30):
#         kit.servo[12].angle = 155-count12
#         count12+=1
#         
#         
#     if (count0 < 10):
#         kit.servo[0].angle = 145+count0
#         count0+=1
#         
#     if (count4 < 30):
#         kit.servo[4].angle = 115+count4
#         count4+=1
#         
#     if (count8 < 10):
#         kit.servo[8].angle = 125-count8
#         count8+=1
#     
#     if count4>=30:
#         break

#pattern1()
# sleep(2)
# resetPattern()
# sleep(0.5)
#pattern2()
# goDownPattern()
# sleep(2)
# resetPattern()
